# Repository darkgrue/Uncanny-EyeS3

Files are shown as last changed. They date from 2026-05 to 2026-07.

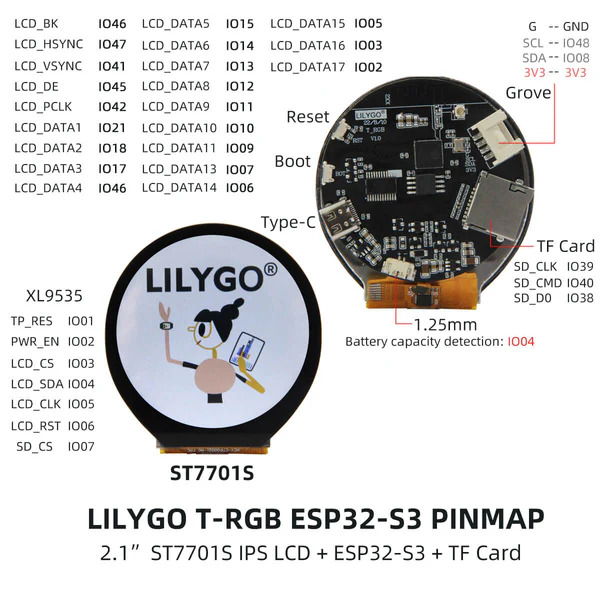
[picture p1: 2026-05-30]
docs/T-RGB-pinmap.jpg

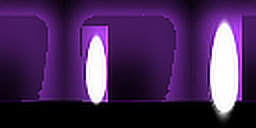
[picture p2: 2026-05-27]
resources/eyes/anime/iris.png

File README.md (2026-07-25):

# Uncanny-EyeS3

A port of the [Adafruit M4 Eyes](https://github.com/adafruit/Adafruit_Learning_System_Guides/tree/main/M4_Eyes) project to the LilyGO T-Display S3 AMOLED and T-RGB, with ESP32-specific rendering optimizations, WiiChuck puppeteering, light-driven pupil control, Gesture & Face Detection Sensor support for gaze direction, and multi-device synchronization over ESP-NOW.

This codebase draws on code and ideas from the following projects:

&emsp;https://github.com/adafruit/Uncanny_Eyes  
&emsp;https://github.com/adafruit/Adafruit_Learning_System_Guides/tree/main/M4_Eyes  
&emsp;https://github.com/chrismiller/TeensyEyes  
&emsp;https://github.com/MichaelMeissner/TeensyEyes/tree/meissner2  

Large portions of this codebase were ported and adapted with the assistance of AI coding tools, based on the logic and structure of the above projects. Sincere thanks to Adafruit, Phillip Burgess, Chris Miller, Michael Meissner, and the respective maintainers and contributors for their original work and for making it freely available to the community.

This project also includes a modified version of the LilyGO Arduino DriveBus Library, altered to correct functional issues.

---

## Supported Hardware

| Board | Display | Controller | Resolution |
| --- | --- | --- | --- |
| [LilyGo T-Display S3 AMOLED](https://lilygo.cc/en-us/products/t-display-s3-amoled-1-64?variant=45002266345653) | CO5300 (QSPI @ 80 MHz) | ESP32-S3 | 466×466 |
| [LilyGo T-RGB](https://lilygo.cc/en-us/products/t-rgb) | ST7701S (DPI) | ESP32-S3 | 480×480 |

**Optional peripherals:**

- Nintendo Wii Nunchuk (WiiChuck) — I2C puppeteering controller
- LDR photoresistor — ambient light-driven pupil dilation
- MAX44009 I2C ambient light sensor — alternative light sensor for pupil control
- DFRobot Gravity Gesture & Face Detection Sensor — AI face tracking for eye targeting
- MicroSD card — boot-time configuration via `/eyes_config.json` (ESP-NOW channel, security key, MAC allowlist)
- SY6970 — battery fuel gauge / charger (on-board, auto-initialized)

---

## Features

- **Autonomous animation** — saccadic eye movement with a lognormal amplitude distribution, centering bias, and sigmoid velocity easing for naturalistic motion
- **Realistic blinking** — three-phase FSM (close → pause → open) with randomized timing and burst probability
- **WiiChuck puppeteering** — joystick-driven eye targeting with edge-triggered blink/boop and hold commands for close/wide expressions
- **Face tracking** — AI gesture & face sensor directs gaze to the nearest detected face, overriding autonomous movement while yielding to WiiChuck joystick
- **Light sensor pupil control** — LDR photoresistor or MAX44009 I2C sensor drives pupil dilation; falls back to autonomous iris animation when not connected
- **Multi-eye ESP-NOW sync** — one device acts as controller, others follow with interpolated state at up to ~120 FPS; optional shared-key authentication prevents unauthorized devices from joining
- **SD card configuration** — optional `/eyes_config.json` at boot sets ESP-NOW channel, shared key, and MAC allowlist; firmware runs with safe defaults when no card is present
- **Runtime eye switching** — switch between registered eye designs over serial without reflashing
- **Double-buffered PSRAM rendering** — two RGB565 frame buffers with dirty-region tracking minimize display transfer overhead
- **User extension hooks** — `user_setup()` / `user_loop()` for custom sensor integrations

---

## Building

Requires [PlatformIO](https://platformio.org/).

```bash
# Build
pio run -e amoled          # T-Display S3 AMOLED (466×466)
pio run -e trgb            # T-RGB (480×480)

# Build and upload
pio run -e amoled --target upload
pio run -e trgb --target upload

# Serial monitor (115200 baud)
pio device monitor
```

---

## How It Works

### Rendering Pipeline

The firmware runs FreeRTOS tasks across two cores:

- **Core 1 — render task (~120 FPS):** `EyeAnimator::update()` advances the movement, blink, and iris state machines each frame. When `needsRender()` is true, `EyeRenderer::renderFrame()` draws the eye into the current PSRAM render buffer using precomputed polar and displacement lookup tables. Dirty region tracking limits each display transfer to only the pixels that changed.
- **Core 0 — display transfer + `loop()`:** The `eyeXfer` FreeRTOS task (priority 5) waits for a semaphore signal, then calls `directTransfer()` to stream the completed frame buffer to the display over QSPI. This task runs concurrently with rendering on Core 1 — as soon as `renderFrame()` finishes drawing, it signals the transfer task and immediately begins rendering the next frame into the other buffer. Arduino `loop()` also runs on Core 0 and handles serial commands and the 5-second status line.

### Eye Rendering

Each eye is defined by a precomputed set of lookup tables baked into C++ headers by `tablegen.py` and `geneye.py`:

- **Polar angle / distance maps** — map every pixel in the display circle to a polar coordinate in texture space
- **Spherical displacement map** — simulates the curvature of an eyeball
- **Radius lookup table** — `uint8_t[mapRadius²]` precomputed in `begin()`; eliminates `sqrt()` in the hot pixel loop
- **Eyelid tables** (optional) — per-column upper/lower eyelid Y positions for custom lid shapes

Textures are stored in **angle-major layout** (`T[angle * texH + radius]`) so that sequential radius lookups within a scanline are contiguous in memory. `EyeRenderer` builds a 256-entry angle→row pointer table at init time, replacing a per-pixel multiply with a single indexed load.

Per-scanline, zone limits (`xPupilLim`, `xIrisLim`) are computed once via the radius map, so the inner pixel loop uses integer comparisons instead of per-pixel radius checks. All lookup tables (angle map, radius map, iris texture, sclera texture) are copied into DRAM at `begin()` time to avoid PSRAM latency in the hot loop.

The frame buffer is stored big-endian (pre-swapped at write time), allowing the transfer task to stream it directly to the display via GDMA without a DRAM staging copy.

### Eye Movement

`EyeMovement` generates saccades using a lognormal amplitude distribution (matching natural human eye statistics), applies a centering bias after peripheral movements, and eases each movement with a sigmoid curve. Between saccades a configurable fixation pause (default 4–8 s) holds the eye still. When a WiiChuck is attached, direct joystick input overrides the autonomous mode.

### Multi-Eye Sync (ESP-NOW)

Any number of devices running the same firmware can synchronize over ESP-NOW:

1. The device with an active WiiChuck (joystick moved beyond the dead zone) becomes the controller.
2. The controller broadcasts an `EyeSyncMessage` each frame — eye X/Y, pupil factor, blink state, and expression command.
3. Follower devices receive the message and apply it via `EyeInterpolator`, which performs linear interpolation between received states for smooth local playback.
4. If no controller message is received within 100 ms, followers return to autonomous animation.

If no WiiChuck is connected to any device, all units run independently in autonomous mode.

ESP-NOW channel and security (shared key, MAC allowlist) are configured via the SD card config file; see [SD Card Configuration](#sd-card-configuration).

---

## Eye Configuration

### File Layout

Eye definitions live in `resources/eyes/`. Each eye has its own subdirectory:

```text
resources/eyes/
  default_eye/
    default_eye_466.eye    # AMOLED config
    default_eye_480.eye    # T-RGB config
    iris.png               # Optional iris texture
    sclera.png             # Optional sclera texture
    upper_lid.png          # Optional custom eyelid shape (grayscale)
    lower_lid.png
```

### Generating C++ Headers

Run `resources/tools/tablegen.py` to generate C++ header files with precomputed polar maps and displacement maps. These tables are shared across all eyes for a given display size. Header files are placed in `include/display/`.

```bash
# Regenerate for a single display type
python resources/tools/tablegen.py [display_type]

# Regenerate all display types
python resources/tools/tablegen.py -all
```

`display_type` is `default` (240x240), `amoled` (466x466), or `trgb` (480x480).

Output headers are named `display_240.h` (default), `display_466.h` (AMOLED), and `display_480.h` (T-RGB).

### `.eye` Config Format

All size values are fractions (0.0–1.0) of the display's smaller dimension, so a single config works across display sizes.

```json
{
    "name": "default_eye",
    "radiusFraction": 0.5,
    "backColor": 0,
    "squint": 0,
    "pupil": {
        "color": 0,
        "slitRadius": 0,
        "minFraction": 0.35,
        "maxFraction": 1.67
    },
    "iris": {
        "maxFraction": 0.5,
        "color": 65281,
        "angle": 0,
        "spin": 0,
        "iSpin": 0,
        "mirror": false,
        "maxTexW": 256,
        "maxTexH": 116
    },
    "sclera": {
        "color": 65535,
        "angle": 0,
        "spin": 0,
        "iSpin": 0,
        "mirror": false,
        "maxTexW": 128,
        "maxTexH": 64
    },
    "eyelid": {
        "color": 0,
        "normalClosure": 0.15,
        "wideClosure": 1.0,
        "tracking": true
    }
}
```

| Field | Description |
| --- | --- |
| `radiusFraction` | Eye radius as fraction of the smaller screen dimension |
| `backColor` | Background color behind the eye (RGB565) |
| `pupil.slitRadius` | `0.0` = round; fraction of iris radius for slit vertical half-height (e.g. `0.75`) |
| `pupil.minFraction` | Pupil radius at full constriction, as fraction of iris radius (brightest light) |
| `pupil.maxFraction` | Pupil radius at full dilation, as fraction of iris radius (darkest light) |
| `iris.maxFraction` | Iris radius as fraction of eye radius |
| `iris.spin` / `iSpin` | Continuous spin / fixed per-frame spin override |
| `iris.filename` | Optional PNG/BMP texture (relative path, auto-converted to RGB565) |
| `sclera.filename` | Optional sclera texture |
| `eyelid.upperFilename` | Optional custom lid images (upper, lower; must match display) |
| `iris.maxTexW` / `maxTexH` | Cap iris texture dimensions at generation time (pixels). Enforces DRAM budget. |
| `sclera.maxTexW` / `maxTexH` | Cap sclera texture dimensions at generation time (pixels). |
| `eyelid.normalClosure` | Eyelid coverage fraction at rest (0.0–1.0). Default: `0.0` |
| `eyelid.wideClosure` | Eyelid retraction fraction for `eyesWide()` (0.0–1.0). Default: `1.0` |
| `eyelid.tracking` | Eyelids track pupil vertical position. Default: `true` |

`eyelid.normalClosure` sets how much the lids close over the eye in the resting-open position. A value of `0.15` means the lids cover 15 % of the eye radius at rest. `eyesWide()` retracts the lids to the `wideClosure` fraction, making the expression visually distinct from the normal resting gap. The supplied eye definitions use `0.15` (default\_eye), `0.20` (hazel), and `0.05` (eagle).

`geneye.py` prints a DRAM budget warning at generation time if the combined angle map + radius map + iris texture + sclera texture exceeds ~170 KB (the threshold above which textures spill from DRAM into PSRAM and degrade render performance). Use `maxTexW`/`maxTexH` in the `.eye` config to bring an eye within budget.

### Adding a New Eye

1. Create `resources/eyes/<name>/` and write `<name>_466.eye` and `<name>_480.eye`.

2. Generate headers:

   ```bash
   python resources/tools/geneye.py -eye <eye_name>    # Generate header for specific eye
   python resources/tools/geneye.py -all               # Generate headers for all eyes
   python resources/tools/geneye.py -list              # List available eyes
   ```

3. Register in `include/EyeLibrary.h` under both board sections:

   ```cpp
   #include "eyes/<name>_466.h"   // in the AMOLED block
   // add &<name>::eye to s_eyeRegistry[] and increment s_eyeCount
   ```

4. Build and test: `pio run -e amoled` / `pio run -e trgb`.

---

## Runtime Eye Switching

Switch the active eye over serial without reflashing:

```text
E0    → switch to eye index 0 (anime)
E1    → switch to eye index 1 (default_eye)
E2    → switch to eye index 2 (dragon)
E3    → switch to eye index 3 (eagle)
E4    → switch to eye index 4 (hazel)
E5    → switch to eye index 5 (leopard)
```

The command is parsed in `loop()` and calls `EyeAnimator::setEyeIndex()`, which reinitializes the renderer with the new eye definition.

---

## Display Orientation

For builds where the display is physically mounted rotated 180°, send a command over
serial to flip the image. The change applies immediately and lasts for the current
power cycle only — it is never written back to the SD card.

```text
U0    → normal orientation
U1    → upside-down (180° flip)
```

If no display is initialized, the command prints `Display not available.` and has
no effect.

A boot-time default can be set via the `display` section in `/eyes_config.json` —
see [SD Card Configuration](#sd-card-configuration):

```json
{
  "display": {
    "upsideDown": false
  }
}
```

On the AMOLED board this is a single display-controller register write (the panel
itself flips the scan-out), so it costs nothing per frame. On the T-RGB board the
flip is applied during the existing per-row buffer copy in `directTransfer()`,
adding only a per-row pixel reversal rather than any change to the render loop
itself.

---

## WiiChuck Controller

### Wiring

| WiiChuck Pin | T-Display S3 AMOLED | T-RGB |
| --- | --- | --- |
| Data (SDA) | GPIO 7 | GPIO 48 |
| Clock (SCL)  | GPIO 6 | GPIO 8  |
| 3.3V | 3.3V | 3.3V |
| GND | GND | GND |

I2C address: `0x52`, bus speed: 400 kHz.

### Controls

| Input | Behavior |
| --- | --- |
| Joystick (active) | Direct eye position; overrides autonomous movement |
| Joystick (centered) | Returns to autonomous wandering after current saccade finishes |
| Z press | Single blink (edge-triggered) |
| C hold | Eyes go wide — eyelids retract beyond the normal resting gap |
| C + Z (chord) | Boop expression (fires when the second button lands) |

Buttons work independently of the joystick: you can blink or go wide while the joystick is centred.

Joystick values are raw 0–255 with center at 128. A ±10 dead zone prevents drift. Control returns to autonomous mode when the joystick is centered.

The WiiChuck is optional — the firmware prints a warning at startup if not found and continues with autonomous animation.

---

## Light Sensor (Pupil Control)

Two sensor types are supported:

- **LDR photoresistor** — connect a voltage divider to GPIO 5 (`LIGHT_PIN`). Auto-detected at startup by sampling for minimum variance.
- **MAX44009 I2C ambient light sensor** — connected via the I2C bus (same as WiiChuck). Auto-detected on startup.

When a light sensor is connected:

- Bright light → constricted pupil
- Dim light → dilated pupil
- Hippus oscillation (natural pupillary unrest) still applies on top of the sensor-driven baseline
- Transition speed is controlled by `PUPIL_SMOOTH_ALPHA` in `src/animation/EyeMovement.h` (lower = slower)

If no sensor is found, autonomous iris animation is used instead.

---

## Gesture & Face Detection Sensor

The [DFRobot Gravity Offline Edge AI Gesture & Face Detection](https://www.dfrobot.com/product-2914.html) sensor connects to the same I2C bus as the WiiChuck (see [WiiChuck Controller](#wiichuck-controller) for pin assignments). It is auto-detected at startup; if not found, the firmware continues without face tracking.

I2C address: `0x72`.

When at least one face is detected with a confidence score at or above the minimum threshold (default 50 out of 100), the eye tracks the nearest face. When no face is visible the eye returns to autonomous random movement.

Face position is reported in camera pixel coordinates. The default normalization assumes a 320×240 frame; pass custom width/height values to the `GestureFaceInput` constructor if the sensor reports a different resolution. Call `setMinScore()` to adjust the confidence threshold.

---

## SD Card Configuration

An optional MicroSD card provides boot-time configuration without reflashing. The card is read once at startup and then released — it is not required while the firmware is running.

### Pinout

Both boards use the same dedicated SPI pins for the SD card:

| SD Pin | GPIO |
| --- | ---- |
| CS | 38 |
| MOSI | 39 |
| MISO | 40 |
| SCLK | 41 |

### Config File

Place `/eyes_config.json` in the root directory of the card:

```json
{
  "eye": {
    "startIndex": 1
  },
  "display": {
    "upsideDown": false
  },
  "network": {
    "channel": 1,
    "key": "SharedPassphrase",
    "allowed_macs": [
      "AA:BB:CC:DD:EE:FF",
      "11:22:33:44:55:66"
    ],
    "forceController": false
  }
}
```

| Field | Type | Default  | Description |
| --- | --- | --- | --- |
| `eye.startIndex` | int | `0` | Eye index to load at startup; see Runtime Eye Switching for names |
| `display.upsideDown` | bool | `false`  | Boot-time default for a 180-degree flip (see Display Orientation) |
| `network.channel` | int | `1` | ESP-NOW WiFi channel (1–13); must match across all synchronized devices |
| `network.key` | string | _(none)_ | Shared passphrase or 32-hex-digit key; omit to disable authentication |
| `network.allowed_macs` | array  | _(none)_ | MAC allowlist; omit to accept any device with the correct key |
| `network.forceController` | bool | `false`  | Broadcast as controller with no WiiChuck/gesture input attached (see below) |

### Syncing Devices Without a WiiChuck

Normally, a device only broadcasts its eye state over ESP-NOW if it has an active WiiChuck or gesture-tracking input attached — that device becomes the controller, and others follow. If none of your devices have such an input, they'll each run autonomous animation independently and never show any ESP-NOW peers.

To sync two or more purely-autonomous devices, set `network.forceController: true` in the config on exactly **one** device in the group. That device broadcasts its (autonomous) state; the others should leave `forceController` unset (or `false`) so they follow it.

### Key Formats

The `key` field accepts two formats:

- **Passphrase** — any string up to 16 characters, zero-padded internally to 16 bytes.
- **Hex key** — exactly 32 hexadecimal characters (e.g. `"0123456789ABCDEF0123456789ABCDEF"`), decoded directly to 16 raw bytes.

Either format can be used interchangeably as long as the resulting 16-byte value is identical on all devices.

### Security Model

When a `key` is configured, the firmware derives a 32-bit token from it and stamps every outgoing ESP-NOW packet. Incoming packets are silently discarded if:

- The token does not match (sender has a different or absent key).
- An `allowed_macs` list is configured and the sender MAC is not in it.

Devices sharing the same key communicate normally. Devices with different keys — or no key — silently ignore each other without producing errors. If no key is configured, any device on the channel is accepted.

**All devices in a synchronized group must use matching keys.**

The `allowed_macs` list provides an additional layer of access control independent of the key. If both are configured, a packet must pass both checks.

### Graceful Degradation

The firmware starts normally regardless of SD card state:

- No SD card inserted
- Card present but `/eyes_config.json` missing
- Config file present but malformed JSON

In all cases the defaults are used: channel 1, no authentication, all senders accepted. A message is printed to serial indicating which condition was detected.

---

## Input Priority

### Movement Priority

The first active source in the following order controls eye position each frame:

1. **WiiChuck joystick** — when the joystick is tilted beyond the ±10 dead zone, it takes exclusive control and suppresses all other movement sources.
2. **Gesture & face detection** — when a face is detected with sufficient confidence, the eye tracks the face. Control is released immediately when no face is visible.
3. **ESP-NOW network controller** — a paired controller device broadcasts its state; followers apply it when data is fresher than 100 ms.
4. **Autonomous random saccades** — lognormal amplitude distribution with centering bias and sigmoid easing; the default when no input is active.

### Pupil Sizing Priority

Pupil size is driven by whichever source is available:

1. **Light sensor (LDR or MAX44009)** — maps ambient light to pupil dilation at up to 100 Hz with time-based exponential smoothing when connected.
2. **Autonomous iris animation** — simulates natural pupillary unrest using lognormal targets and smoothstep easing when no light sensor is present.

Face detection and ESP-NOW do not affect pupil size.

---

## User Extension Hooks

Implement `user_setup()` and `user_loop()` in `src/user/user_hooks.cpp` to add custom behavior without modifying core code. `user_loop()` runs during the render task — keep it short.

Available expression calls from either hook:

```cpp
eyesBlink();    // trigger a single blink
eyesBoop();     // trigger a boop expression
eyesClose();    // hold eyelids closed
eyesWide();     // hold eyelids wide
eyesNormal();   // return to normal tracking
```

---

## Project Structure

```text
src/
  main.cpp                  # Entry point, FreeRTOS task setup
  eye/
    EyeAnimator             # Central animation state machine
    EyeRenderer             # Per-pixel polar-map rendering, double-buffered PSRAM
    EyelidRenderer          # Eyelid shape rendering (procedural or custom)
    EyeConfig.h             # Runtime configuration struct
  animation/
    EyeMovement             # Saccadic movement with lognormal distribution
    BlinkFSM                # Three-phase blink state machine
  display/
    AMOLEDDisplay           # CO5300 QSPI driver (466×466)
    TRGBDisplay             # ST7701S DPI driver (480×480)
  input/
    WiiChuck                # Wii Nunchuk I2C driver
    LightSensor             # LDR photoresistor pupil control
    GestureFaceInput        # DFRobot Gravity Gesture & Face Detection sensor
  network/
    EyeSync                 # ESP-NOW controller/follower synchronization
  config/
    SDConfig                # SD card boot-time configuration reader
  common/
    DisplayHAL.h            # Abstract display interface
    EyeState.h              # Shared state structs and enums
    DisplayGeometry.h       # Polar maps, circular clipping
  debug/
    DebugOverlay            # FPS + battery HUD (build flag: DEBUG_OVERLAY_ENABLED)
  user/
    user_hooks.cpp          # User extension template

include/
  eyes.h                    # EyeDefinition struct and helper macros
  EyeLibrary.h              # Eye registry (s_eyeRegistry[], s_eyeCount)
  BoardPins.h               # GPIO pin definitions per board
  eyes/
    *_466.h                 # Generated AMOLED eye headers
    *_480.h                 # Generated T-RGB eye headers

resources/
  tools/
    tablegen.py             # Display polar-map / displacement table generator
    geneye.py               # Eye header generator (angle-major textures, DRAM budget check)
    test_geneye_texture.py  # Texture layout unit tests
  eyes/
    <eye_name>/
      <eye_name>_466.eye    # AMOLED eye config
      <eye_name>_480.eye    # T-RGB eye config
      *.png / *.bmp         # Optional textures and eyelid images
```

---

## Build Flags

Defined in `platformio.ini` under `[esp32base]`:

| Flag | Purpose |
| --- | --- |
| `FDEBUG` | Enable debug serial output |
| `DEBUG_OVERLAY_ENABLED` | Show FPS/battery HUD on display |
| `DEBUG_FPS_ENABLED` | Print FPS and render/transfer timing to serial |
| `CORE_DEBUG_LEVEL=3` | ESP-IDF log verbosity (info) |
| `BUILDVER=0.0.1` | Embedded firmware version string |
| `ESP32QSPI_MAX_PIXELS_AT_ONCE=16384`  | SPI DMA chunk size (patched library); 16384 pixels = 32 KB buffer |

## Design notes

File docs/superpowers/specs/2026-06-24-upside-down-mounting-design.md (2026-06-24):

# Upside-Down Mounting Design

**Date:** 2026-06-24
**Status:** Approved
**Scope:** `DisplayHAL`, `AMOLEDDisplay`, `TRGBDisplay`, `SDConfig`, `EyeConfig`, `main.cpp`

---

## Problem

Some physical builds need a display mounted rotated 180° relative to its native
orientation (e.g. cable routing constraints in the housing). The firmware needs a
way to compensate for this — flipping the displayed image 180° — without adding
per-pixel cost to the 120 FPS render/transfer hot path.

The setting must be:
- Per physical display (a property of how *this device* is mounted, not of which
  eye graphic or eye index is currently loaded).
- Settable at runtime via serial command, taking effect immediately.
- Configurable with a boot-time default via `/eyes_config.json` on the SD card.
- Session-only — runtime changes do not persist back to the SD card.

---

## Solution: Flip in the display layer, not the renderer

`EyeRenderer` always renders in standard top-left-origin orientation — unchanged.
Each `DisplayHAL` implementation is already responsible for getting that buffer onto
its physical panel; the 180° compensation belongs there; the two backends need
different mechanisms because their hardware differs.

`DisplayHAL::setRotation(uint8_t rotation)` already exists in the interface
([DisplayHAL.h:54](../../../src/common/DisplayHAL.h)). `rotation = 2` is reused as
the "180°" value on both backends, consistent with the existing Arduino_GFX
convention. No new interface method is added.

### AMOLED (CO5300, QSPI) — already correct, no code change

`AMOLEDDisplay::setRotation()` ([AMOLEDDisplay.cpp:247-254](../../../src/display/AMOLEDDisplay.cpp))
calls `m_gfx->setRotation(rotation)`. For the CO5300, `Arduino_CO5300::setRotation(2)`
writes the controller's MADCTL register with both X- and Y-axis flip bits
([Arduino_CO5300.cpp:41-62](../../../.pio/libdeps/amoled/GFX%20Library%20for%20Arduino/src/display/Arduino_CO5300.cpp)).
This is a single register write — the display controller itself flips the image as
it scans into the physical panel. Because `EyeRenderer`'s async transfer always blits
the full `0,0 → displaySize,displaySize` buffer ([EyeRenderer.cpp:415](../../../src/eye/EyeRenderer.cpp)),
one register write at orientation-change time reorients everything (eye content and
debug overlay) with zero ongoing per-frame cost. `_xStart`/`_yStart` offset handling
for rotation 2 resolves to `(COL_OFFSET2, ROW_OFFSET2)` = `(0, 0)` for this panel's
constructor parameters, so no addressing-window correction is needed.

### T-RGB (ST7701S, DPI) — flip applied during the existing per-row copy

`TRGBDisplay::setRotation()` ([TRGBDisplay.cpp:128-134](../../../src/display/TRGBDisplay.cpp))
currently only forwards to `gfx->setRotation()`, which sets a software variable in
the base `Arduino_GFX` class — it does **not** send any MADCTL-equivalent command
(`Arduino_RGB_Display` does not override `setRotation`), and it has no effect on
`directTransfer`'s raw `memcpy` into the PSRAM framebuffer.

Change `TRGBDisplay::setRotation()` to:
1. Keep calling `gfx->setRotation(rotation)` — this keeps the debug overlay
   (`fillRect`/`drawString`, which go through normal Arduino_GFX draw calls) correctly
   placed after a flip. Low frequency; cost is irrelevant.
2. Store `m_rotation180 = (rotation == 2)` on the `TRGBDisplay` instance.

Change `TRGBDisplay::directTransfer()` ([TRGBDisplay.cpp:190-209](../../../src/display/TRGBDisplay.cpp))
to branch on `m_rotation180`:
- **Normal (false):** unchanged — per-row `memcpy`.
- **Flipped (true):** iterate source rows back-to-front (`srcH-1` down to `0`) when
  computing the destination row — free, same total `memcpy` byte count, just a
  different row-to-row mapping — and within each row, copy pixels in reverse order
  (`dstRow[w-1-i] = srcRow[i]`). This is the one place that adds real per-frame cost:
  a per-pixel copy loop instead of a single `memcpy` for each row, on a ≤480-pixel
  row, once per frame. Negligible next to the per-pixel rendering cost already paid
  earlier in the same frame, and it does not touch `EyeRenderer`'s hot loop at all.

---

## Runtime control

Add a new single-character serial command to the existing dispatcher in
`main.cpp` ([main.cpp:677-692](../../../src/main.cpp)), alongside the existing `E<n>`
eye-switch command:

```cpp
else if (c == 'U')
{
  int flag = Serial.parseInt();
  s_display->setRotation(flag ? 2 : 0);
  Serial.printf("Display %s\n", flag ? "upside-down" : "normal");
}
```

`U1` sets upside-down, `U0` restores normal. Takes effect immediately. This is
session-only — it does not write back to the SD card.

---

## Boot-time default: `/eyes_config.json`

Add a new top-level `display` section (separate from the existing `eye` section,
since this is a property of the physical device, not of the eye graphic or index):

```json
{
  "display": {
    "upsideDown": false
  }
}
```

**`SDConfig` changes:**
- `DeviceConfig` ([SDConfig.h:47-56](../../../src/config/SDConfig.h)) gains
  `bool displayUpsideDown;` (default `false`, set in `applyDefaults()`).
- `SDConfig::load()` ([SDConfig.cpp:25-112](../../../src/config/SDConfig.cpp)) gains a
  `display` section parse block, mirroring the existing `eye`/`network` block style:
  ```cpp
  JsonObject disp = doc["display"];
  if (!disp.isNull())
  {
    cfg.displayUpsideDown = disp["upsideDown"] | false;
  }
  ```

**Applying the default:** in `main.cpp` setup, after `s_display` is assigned and
`begin()` has run, call:
```cpp
s_display->setRotation(s_config.displayUpsideDown ? 2 : 0);
```
This is the same code path as the runtime `U` command, so behavior is identical
whether the orientation is set at boot or live.

`EyeProjectConfig` ([EyeConfig.h](../../../src/eye/EyeConfig.h)) is not changed —
orientation is consumed directly from `DeviceConfig` into `DisplayHAL`, not routed
through the animator/renderer config struct, since `EyeRenderer` is intentionally
untouched by this feature.

---

## Files Changed

| File | Nature of change |
|---|---|
| `src/display/TRGBDisplay.h` / `.cpp` | `setRotation()` stores `m_rotation180`; `directTransfer()` branches to a reversed row+pixel copy when flipped |
| `src/display/AMOLEDDisplay.h` / `.cpp` | No change — existing `setRotation()` already sufficient |
| `src/common/DisplayHAL.h` | No change — reuses existing `setRotation(uint8_t)` |
| `src/config/SDConfig.h` / `.cpp` | New `DeviceConfig::displayUpsideDown` field; new `display` JSON section parsing |
| `src/main.cpp` | New `U<0|1>` serial command; apply `s_config.displayUpsideDown` to `s_display` once at startup |

No changes to `EyeRenderer`, `EyelidRenderer`, `EyeAnimator`, `eyes.h`, or any
generated eye headers — this feature is entirely contained in the display/config
layer.

---

## Testing

- **AMOLED:** send `U1` over serial, confirm the eye and debug overlay (if enabled)
  both appear rotated 180°; send `U0`, confirm restoration. Confirm FPS is unaffected
  (expected — hardware-only change).
- **T-RGB:** same `U1`/`U0` check. Measure `directTransfer` duration before/after to
  confirm the reversed-copy cost is negligible relative to total frame time.
- **SD config:** set `"display": {"upsideDown": true}` in `/eyes_config.json`, confirm
  boot starts flipped; confirm a runtime `U0` overrides it for the session without
  rewriting the file.
- **No SD card / missing `display` section:** confirm default is normal orientation
  (false), matching existing `applyDefaults()` behavior for absent sections.

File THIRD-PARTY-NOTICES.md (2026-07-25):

# Third-Party Notices

This project incorporates open-source third-party software. The notices and licenses for these dependencies are detailed below.

---

## 1. Uncanny_Eyes
* **Source:** https://github.com/adafruit/Uncanny_Eyes
* **Copyright:** Written by Phil Burgess / Paint Your Dragon for Adafruit Industries.

MIT license. [LICENSE file not provided by author.]

## 2. Adafruit_Learning_System_Guides / M4_Eyes
* **Source:** https://github.com/adafruit/Adafruit_Learning_System_Guides/tree/main/M4_Eyes
* **Copyright:** 2019 Phillip Burgess for Adafruit Industries.

MIT License

Copyright (c) 2018 Adafruit Industries

Permission is hereby granted, free of charge, to any person obtaining a copy
of this software and associated documentation files (the "Software"), to deal
in the Software without restriction, including without limitation the rights
to use, copy, modify, merge, publish, distribute, sublicense, and/or sell
copies of the Software, and to permit persons to whom the Software is
furnished to do so, subject to the following conditions:

The above copyright notice and this permission notice shall be included in all
copies or substantial portions of the Software.

THE SOFTWARE IS PROVIDED "AS IS", WITHOUT WARRANTY OF ANY KIND, EXPRESS OR
IMPLIED, INCLUDING BUT NOT LIMITED TO THE WARRANTIES OF MERCHANTABILITY,
FITNESS FOR A PARTICULAR PURPOSE AND NONINFRINGEMENT. IN NO EVENT SHALL THE
AUTHORS OR COPYRIGHT HOLDERS BE LIABLE FOR ANY CLAIM, DAMAGES OR OTHER
LIABILITY, WHETHER IN AN ACTION OF CONTRACT, TORT OR OTHERWISE, ARISING FROM,
OUT OF OR IN CONNECTION WITH THE SOFTWARE OR THE USE OR OTHER DEALINGS IN THE
SOFTWARE.

## 3. TeensyEyes
* **Source:** https://github.com/chrismiller/TeensyEyes
* **Copyright:** 2022 Chris Miller

MIT License

Copyright (c) 2022 Chris Miller

Permission is hereby granted, free of charge, to any person obtaining a copy
of this software and associated documentation files (the "Software"), to deal
in the Software without restriction, including without limitation the rights
to use, copy, modify, merge, publish, distribute, sublicense, and/or sell
copies of the Software, and to permit persons to whom the Software is
furnished to do so, subject to the following conditions:

The above copyright notice and this permission notice shall be included in all
copies or substantial portions of the Software.

THE SOFTWARE IS PROVIDED "AS IS", WITHOUT WARRANTY OF ANY KIND, EXPRESS OR
IMPLIED, INCLUDING BUT NOT LIMITED TO THE WARRANTIES OF MERCHANTABILITY,
FITNESS FOR A PARTICULAR PURPOSE AND NONINFRINGEMENT. IN NO EVENT SHALL THE
AUTHORS OR COPYRIGHT HOLDERS BE LIABLE FOR ANY CLAIM, DAMAGES OR OTHER
LIABILITY, WHETHER IN AN ACTION OF CONTRACT, TORT OR OTHERWISE, ARISING FROM,
OUT OF OR IN CONNECTION WITH THE SOFTWARE OR THE USE OR OTHER DEALINGS IN THE
SOFTWARE.

## 4. TeensyEyes
* **Source:** https://github.com/MichaelMeissner/TeensyEyes/tree/meissner2
* **Copyright:** Michael Meissner

MIT License

Copyright (c) 2022 Chris Miller [sic]

Permission is hereby granted, free of charge, to any person obtaining a copy
of this software and associated documentation files (the "Software"), to deal
in the Software without restriction, including without limitation the rights
to use, copy, modify, merge, publish, distribute, sublicense, and/or sell
copies of the Software, and to permit persons to whom the Software is
furnished to do so, subject to the following conditions:

The above copyright notice and this permission notice shall be included in all
copies or substantial portions of the Software.

THE SOFTWARE IS PROVIDED "AS IS", WITHOUT WARRANTY OF ANY KIND, EXPRESS OR
IMPLIED, INCLUDING BUT NOT LIMITED TO THE WARRANTIES OF MERCHANTABILITY,
FITNESS FOR A PARTICULAR PURPOSE AND NONINFRINGEMENT. IN NO EVENT SHALL THE
AUTHORS OR COPYRIGHT HOLDERS BE LIABLE FOR ANY CLAIM, DAMAGES OR OTHER
LIABILITY, WHETHER IN AN ACTION OF CONTRACT, TORT OR OTHERWISE, ARISING FROM,
OUT OF OR IN CONNECTION WITH THE SOFTWARE OR THE USE OR OTHER DEALINGS IN THE
SOFTWARE.

## 5. Arduino_DriveBus
* **Source:** https://github.com/Xinyuan-LilyGO/T-Display-S3-AMOLED-1.43-1.75/tree/main/libraries/Arduino_DriveBus
* **Copyright:** LilyGO

                    GNU GENERAL PUBLIC LICENSE
                       Version 3, 29 June 2007

 Copyright (C) 2007 Free Software Foundation, Inc. <https://fsf.org/>
 Everyone is permitted to copy and distribute verbatim copies
 of this license document, but changing it is not allowed.

                            Preamble

  The GNU General Public License is a free, copyleft license for
software and other kinds of works.

  The licenses for most software and other practical works are designed
to take away your freedom to share and change the works.  By contrast,
the GNU General Public License is intended to guarantee your freedom to
share and change all versions of a program--to make sure it remains free
software for all its users.  We, the Free Software Foundation, use the
GNU General Public License for most of our software; it applies also to
any other work released this way by its authors.  You can apply it to
your programs, too.

  When we speak of free software, we are referring to freedom, not
price.  Our General Public Licenses are designed to make sure that you
have the freedom to distribute copies of free software (and charge for
them if you wish), that you receive source code or can get it if you
want it, that you can change the software or use pieces of it in new
free programs, and that you know you can do these things.

  To protect your rights, we need to prevent others from denying you
these rights or asking you to surrender the rights.  Therefore, you have
certain responsibilities if you distribute copies of the software, or if
you modify it: responsibilities to respect the freedom of others.

  For example, if you distribute copies of such a program, whether
gratis or for a fee, you must pass on to the recipients the same
freedoms that you received.  You must make sure that they, too, receive
or can get the source code.  And you must show them these terms so they
know their rights.

  Developers that use the GNU GPL protect your rights with two steps:
(1) assert copyright on the software, and (2) offer you this License
giving you legal permission to copy, distribute and/or modify it.

  For the developers' and authors' protection, the GPL clearly explains
that there is no warranty for this free software.  For both users' and
authors' sake, the GPL requires that modified versions be marked as
changed, so that their problems will not be attributed erroneously to
authors of previous versions.

  Some devices are designed to deny users access to install or run
modified versions of the software inside them, although the manufacturer
can do so.  This is fundamentally incompatible with the aim of
protecting users' freedom to change the software.  The systematic
pattern of such abuse occurs in the area of products for individuals to
use, which is precisely where it is most unacceptable.  Therefore, we
have designed this version of the GPL to prohibit the practice for those
products.  If such problems arise substantially in other domains, we
stand ready to extend this provision to those domains in future versions
of the GPL, as needed to protect the freedom of users.

  Finally, every program is threatened constantly by software patents.
States should not allow patents to restrict development and use of
software on general-purpose computers, but in those that do, we wish to
avoid the special danger that patents applied to a free program could
make it effectively proprietary.  To prevent this, the GPL assures that
patents cannot be used to render the program non-free.

  The precise terms and conditions for copying, distribution and
modification follow.

                       TERMS AND CONDITIONS

  0. Definitions.

  "This License" refers to version 3 of the GNU General Public License.

  "Copyright" also means copyright-like laws that apply to other kinds of
works, such as semiconductor masks.

  "The Program" refers to any copyrightable work licensed under this
License.  Each licensee is addressed as "you".  "Licensees" and
"recipients" may be individuals or organizations.

  To "modify" a work means to copy from or adapt all or part of the work
in a fashion requiring copyright permission, other than the making of an
exact copy.  The resulting work is called a "modified version" of the
earlier work or a work "based on" the earlier work.

  A "covered work" means either the unmodified Program or a work based
on the Program.

  To "propagate" a work means to do anything with it that, without
permission, would make you directly or secondarily liable for
infringement under applicable copyright law, except executing it on a
computer or modifying a private copy.  Propagation includes copying,
distribution (with or without modification), making available to the
public, and in some countries other activities as well.

  To "convey" a work means any kind of propagation that enables other
parties to make or receive copies.  Mere interaction with a user through
a computer network, with no transfer of a copy, is not conveying.

  An interactive user interface displays "Appropriate Legal Notices"
to the extent that it includes a convenient and prominently visible
feature that (1) displays an appropriate copyright notice, and (2)
tells the user that there is no warranty for the work (except to the
extent that warranties are provided), that licensees may convey the
work under this License, and how to view a copy of this License.  If
the interface presents a list of user commands or options, such as a
menu, a prominent item in the list meets this criterion.

  1. Source Code.

  The "source code" for a work means the preferred form of the work
for making modifications to it.  "Object code" means any non-source
form of a work.

  A "Standard Interface" means an interface that either is an official
standard defined by a recognized standards body, or, in the case of
interfaces specified for a particular programming language, one that
is widely used among developers working in that language.

  The "System Libraries" of an executable work include anything, other
than the work as a whole, that (a) is included in the normal form of
packaging a Major Component, but which is not part of that Major
Component, and (b) serves only to enable use of the work with that
Major Component, or to implement a Standard Interface for which an
implementation is available to the public in source code form.  A
"Major Component", in this context, means a major essential component
(kernel, window system, and so on) of the specific operating system
(if any) on which the executable work runs, or a compiler used to
produce the work, or an object code interpreter used to run it.

  The "Corresponding Source" for a work in object code form means all
the source code needed to generate, install, and (for an executable
work) run the object code and to modify the work, including scripts to
control those activities.  However, it does not include the work's
System Libraries, or general-purpose tools or generally available free
programs which are used unmodified in performing those activities but
which are not part of the work.  For example, Corresponding Source
includes interface definition files associated with source files for
the work, and the source code for shared libraries and dynamically
linked subprograms that the work is specifically designed to require,
such as by intimate data communication or control flow between those
subprograms and other parts of the work.

  The Corresponding Source need not include anything that users
can regenerate automatically from other parts of the Corresponding
Source.

  The Corresponding Source for a work in source code form is that
same work.

  2. Basic Permissions.

  All rights granted under this License are granted for the term of
copyright on the Program, and are irrevocable provided the stated
conditions are met.  This License explicitly affirms your unlimited
permission to run the unmodified Program.  The output from running a
covered work is covered by this License only if the output, given its
content, constitutes a covered work.  This License acknowledges your
rights of fair use or other equivalent, as provided by copyright law.

  You may make, run and propagate covered works that you do not
convey, without conditions so long as your license otherwise remains
in force.  You may convey covered works to others for the sole purpose
of having them make modifications exclusively for you, or provide you
with facilities for running those works, provided that you comply with
the terms of this License in conveying all material for which you do
not control copyright.  Those thus making or running the covered works
for you must do so exclusively on your behalf, under your direction
and control, on terms that prohibit them from making any copies of
your copyrighted material outside their relationship with you.

  Conveying under any other circumstances is permitted solely under
the conditions stated below.  Sublicensing is not allowed; section 10
makes it unnecessary.

  3. Protecting Users' Legal Rights From Anti-Circumvention Law.

  No covered work shall be deemed part of an effective technological
measure under any applicable law fulfilling obligations under article
11 of the WIPO copyright treaty adopted on 20 December 1996, or
similar laws prohibiting or restricting circumvention of such
measures.

  When you convey a covered work, you waive any legal power to forbid
circumvention of technological measures to the extent such circumvention
is effected by exercising rights under this License with respect to
the covered work, and you disclaim any intention to limit operation or
modification of the work as a means of enforcing, against the work's
users, your or third parties' legal rights to forbid circumvention of
technological measures.

  4. Conveying Verbatim Copies.

  You may convey verbatim copies of the Program's source code as you
receive it, in any medium, provided that you conspicuously and
appropriately publish on each copy an appropriate copyright notice;
keep intact all notices stating that this License and any
non-permissive terms added in accord with section 7 apply to the code;
keep intact all notices of the absence of any warranty; and give all
recipients a copy of this License along with the Program.

  You may charge any price or no price for each copy that you convey,
and you may offer support or warranty protection for a fee.

  5. Conveying Modified Source Versions.

  You may convey a work based on the Program, or the modifications to
produce it from the Program, in the form of source code under the
terms of section 4, provided that you also meet all of these conditions:

    a) The work must carry prominent notices stating that you modified
    it, and giving a relevant date.

    b) The work must carry prominent notices stating that it is
    released under this License and any conditions added under section
    7.  This requirement modifies the requirement in section 4 to
    "keep intact all notices".

    c) You must license the entire work, as a whole, under this
    License to anyone who comes into possession of a copy.  This
    License will therefore apply, along with any applicable section 7
    additional terms, to the whole of the work, and all its parts,
    regardless of how they are packaged.  This License gives no
    permission to license the work in any other way, but it does not
    invalidate such permission if you have separately received it.

    d) If the work has interactive user interfaces, each must display
    Appropriate Legal Notices; however, if the Program has interactive
    interfaces that do not display Appropriate Legal Notices, your
    work need not make them do so.

  A compilation of a covered work with other separate and independent
works, which are not by their nature extensions of the covered work,
and which are not combined with it such as to form a larger program,
in or on a volume of a storage or distribution medium, is called an
"aggregate" if the compilation and its resulting copyright are not
used to limit the access or legal rights of the compilation's users
beyond what the individual works permit.  Inclusion of a covered work
in an aggregate does not cause this License to apply to the other
parts of the aggregate.

  6. Conveying Non-Source Forms.

  You may convey a covered work in object code form under the terms
of sections 4 and 5, provided that you also convey the
machine-readable Corresponding Source under the terms of this License,
in one of these ways:

    a) Convey the object code in, or embodied in, a physical product
    (including a physical distribution medium), accompanied by the
    Corresponding Source fixed on a durable physical medium
    customarily used for software interchange.

    b) Convey the object code in, or embodied in, a physical product
    (including a physical distribution medium), accompanied by a
    written offer, valid for at least three years and valid for as
    long as you offer spare parts or customer support for that product
    model, to give anyone who possesses the object code either (1) a
    copy of the Corresponding Source for all the software in the
    product that is covered by this License, on a durable physical
    medium customarily used for software interchange, for a price no
    more than your reasonable cost of physically performing this
    conveying of source, or (2) access to copy the
    Corresponding Source from a network server at no charge.

    c) Convey individual copies of the object code with a copy of the
    written offer to provide the Corresponding Source.  This
    alternative is allowed only occasionally and noncommercially, and
    only if you received the object code with such an offer, in accord
    with subsection 6b.

    d) Convey the object code by offering access from a designated
    place (gratis or for a charge), and offer equivalent access to the
    Corresponding Source in the same way through the same place at no
    further charge.  You need not require recipients to copy the
    Corresponding Source along with the object code.  If the place to
    copy the object code is a network server, the Corresponding Source
    may be on a different server (operated by you or a third party)
    that supports equivalent copying facilities, provided you maintain
    clear directions next to the object code saying where to find the
    Corresponding Source.  Regardless of what server hosts the
    Corresponding Source, you remain obligated to ensure that it is
    available for as long as needed to satisfy these requirements.

    e) Convey the object code using peer-to-peer transmission, provided
    you inform other peers where the object code and Corresponding
    Source of the work are being offered to the general public at no
    charge under subsection 6d.

  A separable portion of the object code, whose source code is excluded
from the Corresponding Source as a System Library, need not be
included in conveying the object code work.

  A "User Product" is either (1) a "consumer product", which means any
tangible personal property which is normally used for personal, family,
or household purposes, or (2) anything designed or sold for incorporation
into a dwelling.  In determining whether a product is a consumer product,
doubtful cases shall be resolved in favor of coverage.  For a particular
product received by a particular user, "normally used" refers to a
typical or common use of that class of product, regardless of the status
of the particular user or of the way in which the particular user
actually uses, or expects or is expected to use, the product.  A product
is a consumer product regardless of whether the product has substantial
commercial, industrial or non-consumer uses, unless such uses represent
the only significant mode of use of the product.

  "Installation Information" for a User Product means any methods,
procedures, authorization keys, or other information required to install
and execute modified versions of a covered work in that User Product from
a modified version of its Corresponding Source.  The information must
suffice to ensure that the continued functioning of the modified object
code is in no case prevented or interfered with solely because
modification has been made.

  If you convey an object code work under this section in, or with, or
specifically for use in, a User Product, and the conveying occurs as
part of a transaction in which the right of possession and use of the
User Product is transferred to the recipient in perpetuity or for a
fixed term (regardless of how the transaction is characterized), the
Corresponding Source conveyed under this section must be accompanied
by the Installation Information.  But this requirement does not apply
if neither you nor any third party retains the ability to install
modified object code on the User Product (for example, the work has
been installed in ROM).

  The requirement to provide Installation Information does not include a
requirement to continue to provide support service, warranty, or updates
for a work that has been modified or installed by the recipient, or for
the User Product in which it has been modified or installed.  Access to a
network may be denied when the modification itself materially and
adversely affects the operation of the network or violates the rules and
protocols for communication across the network.

  Corresponding Source conveyed, and Installation Information provided,
in accord with this section must be in a format that is publicly
documented (and with an implementation available to the public in
source code form), and must require no special password or key for
unpacking, reading or copying.

  7. Additional Terms.

  "Additional permissions" are terms that supplement the terms of this
License by making exceptions from one or more of its conditions.
Additional permissions that are applicable to the entire Program shall
be treated as though they were included in this License, to the extent
that they are valid under applicable law.  If additional permissions
apply only to part of the Program, that part may be used separately
under those permissions, but the entire Program remains governed by
this License without regard to the additional permissions.

  When you convey a copy of a covered work, you may at your option
remove any additional permissions from that copy, or from any part of
it.  (Additional permissions may be written to require their own
removal in certain cases when you modify the work.)  You may place
additional permissions on material, added by you to a covered work,
for which you have or can give appropriate copyright permission.

  Notwithstanding any other provision of this License, for material you
add to a covered work, you may (if authorized by the copyright holders of
that material) supplement the terms of this License with terms:

    a) Disclaiming warranty or limiting liability differently from the
    terms of sections 15 and 16 of this License; or

    b) Requiring preservation of specified reasonable legal notices or
    author attributions in that material or in the Appropriate Legal
    Notices displayed by works containing it; or

    c) Prohibiting misrepresentation of the origin of that material, or
    requiring that modified versions of such material be marked in
    reasonable ways as different from the original version; or

    d) Limiting the use for publicity purposes of names of licensors or
    authors of the material; or

    e) Declining to grant rights under trademark law for use of some
    trade names, trademarks, or service marks; or

    f) Requiring indemnification of licensors and authors of that
    material by anyone who conveys the material (or modified versions of
    it) with contractual assumptions of liability to the recipient, for
    any liability that these contractual assumptions directly impose on
    those licensors and authors.

  All other non-permissive additional terms are considered "further
restrictions" within the meaning of section 10.  If the Program as you
received it, or any part of it, contains a notice stating that it is
governed by this License along with a term that is a further
restriction, you may remove that term.  If a license document contains
a further restriction but permits relicensing or conveying under this
License, you may add to a covered work material governed by the terms
of that license document, provided that the further restriction does
not survive such relicensing or conveying.

  If you add terms to a covered work in accord with this section, you
must place, in the relevant source files, a statement of the
additional terms that apply to those files, or a notice indicating
where to find the applicable terms.

  Additional terms, permissive or non-permissive, may be stated in the
form of a separately written license, or stated as exceptions;
the above requirements apply either way.

  8. Termination.

  You may not propagate or modify a covered work except as expressly
provided under this License.  Any attempt otherwise to propagate or
modify it is void, and will automatically terminate your rights under
this License (including any patent licenses granted under the third
paragraph of section 11).

  However, if you cease all violation of this License, then your
license from a particular copyright holder is reinstated (a)
provisionally, unless and until the copyright holder explicitly and
finally terminates your license, and (b) permanently, if the copyright
holder fails to notify you of the violation by some reasonable means
prior to 60 days after the cessation.

  Moreover, your license from a particular copyright holder is
reinstated permanently if the copyright holder notifies you of the
violation by some reasonable means, this is the first time you have
received notice of violation of this License (for any work) from that
copyright holder, and you cure the violation prior to 30 days after
your receipt of the notice.

  Termination of your rights under this section does not terminate the
licenses of parties who have received copies or rights from you under
this License.  If your rights have been terminated and not permanently
reinstated, you do not qualify to receive new licenses for the same
material under section 10.

  9. Acceptance Not Required for Having Copies.

  You are not required to accept this License in order to receive or
run a copy of the Program.  Ancillary propagation of a covered work
occurring solely as a consequence of using peer-to-peer transmission
to receive a copy likewise does not require acceptance.  However,
nothing other than this License grants you permission to propagate or
modify any covered work.  These actions infringe copyright if you do
not accept this License.  Therefore, by modifying or propagating a
covered work, you indicate your acceptance of this License to do so.

  10. Automatic Licensing of Downstream Recipients.

  Each time you convey a covered work, the recipient automatically
receives a license from the original licensors, to run, modify and
propagate that work, subject to this License.  You are not responsible
for enforcing compliance by third parties with this License.

  An "entity transaction" is a transaction transferring control of an
organization, or substantially all assets of one, or subdividing an
organization, or merging organizations.  If propagation of a covered
work results from an entity transaction, each party to that
transaction who receives a copy of the work also receives whatever
licenses to the work the party's predecessor in interest had or could
give under the previous paragraph, plus a right to possession of the
Corresponding Source of the work from the predecessor in interest, if
the predecessor has it or can get it with reasonable efforts.

  You may not impose any further restrictions on the exercise of the
rights granted or affirmed under this License.  For example, you may
not impose a license fee, royalty, or other charge for exercise of
rights granted under this License, and you may not initiate litigation
(including a cross-claim or counterclaim in a lawsuit) alleging that
any patent claim is infringed by making, using, selling, offering for
sale, or importing the Program or any portion of it.

  11. Patents.

  A "contributor" is a copyright holder who authorizes use under this
License of the Program or a work on which the Program is based.  The
work thus licensed is called the contributor's "contributor version".

  A contributor's "essential patent claims" are all patent claims
owned or controlled by the contributor, whether already acquired or
hereafter acquired, that would be infringed by some manner, permitted
by this License, of making, using, or selling its contributor version,
but do not include claims that would be infringed only as a
consequence of further modification of the contributor version.  For
purposes of this definition, "control" includes the right to grant
patent sublicenses in a manner consistent with the requirements of
this License.

  Each contributor grants you a non-exclusive, worldwide, royalty-free
patent license under the contributor's essential patent claims, to
make, use, sell, offer for sale, import and otherwise run, modify and
propagate the contents of its contributor version.

  In the following three paragraphs, a "patent license" is any express
agreement or commitment, however denominated, not to enforce a patent
(such as an express permission to practice a patent or covenant not to
sue for patent infringement).  To "grant" such a patent license to a
party means to make such an agreement or commitment not to enforce a
patent against the party.

  If you convey a covered work, knowingly relying on a patent license,
and the Corresponding Source of the work is not available for anyone
to copy, free of charge and under the terms of this License, through a
publicly available network server or other readily accessible means,
then you must either (1) cause the Corresponding Source to be so
available, or (2) arrange to deprive yourself of the benefit of the
patent license for this particular work, or (3) arrange, in a manner
consistent with the requirements of this License, to extend the patent
license to downstream recipients.  "Knowingly relying" means you have
actual knowledge that, but for the patent license, your conveying the
covered work in a country, or your recipient's use of the covered work
in a country, would infringe one or more identifiable patents in that
country that you have reason to believe are valid.

  If, pursuant to or in connection with a single transaction or
arrangement, you convey, or propagate by procuring conveyance of, a
covered work, and grant a patent license to some of the parties
receiving the covered work authorizing them to use, propagate, modify
or convey a specific copy of the covered work, then the patent license
you grant is automatically extended to all recipients of the covered
work and works based on it.

  A patent license is "discriminatory" if it does not include within
the scope of its coverage, prohibits the exercise of, or is
conditioned on the non-exercise of one or more of the rights that are
specifically granted under this License.  You may not convey a covered
work if you are a party to an arrangement with a third party that is
in the business of distributing software, under which you make payment
to the third party based on the extent of your activity of conveying
the work, and under which the third party grants, to any of the
parties who would receive the covered work from you, a discriminatory
patent license (a) in connection with copies of the covered work
conveyed by you (or copies made from those copies), or (b) primarily
for and in connection with specific products or compilations that
contain the covered work, unless you entered into that arrangement,
or that patent license was granted, prior to 28 March 2007.

  Nothing in this License shall be construed as excluding or limiting
any implied license or other defenses to infringement that may
otherwise be available to you under applicable patent law.

  12. No Surrender of Others' Freedom.

  If conditions are imposed on you (whether by court order, agreement or
otherwise) that contradict the conditions of this License, they do not
excuse you from the conditions of this License.  If you cannot convey a
covered work so as to satisfy simultaneously your obligations under this
License and any other pertinent obligations, then as a consequence you may
not convey it at all.  For example, if you agree to terms that obligate you
to collect a royalty for further conveying from those to whom you convey
the Program, the only way you could satisfy both those terms and this
License would be to refrain entirely from conveying the Program.

  13. Use with the GNU Affero General Public License.

  Notwithstanding any other provision of this License, you have
permission to link or combine any covered work with a work licensed
under version 3 of the GNU Affero General Public License into a single
combined work, and to convey the resulting work.  The terms of this
License will continue to apply to the part which is the covered work,
but the special requirements of the GNU Affero General Public License,
section 13, concerning interaction through a network will apply to the
combination as such.

  14. Revised Versions of this License.

  The Free Software Foundation may publish revised and/or new versions of
the GNU General Public License from time to time.  Such new versions will
be similar in spirit to the present version, but may differ in detail to
address new problems or concerns.

  Each version is given a distinguishing version number.  If the
Program specifies that a certain numbered version of the GNU General
Public License "or any later version" applies to it, you have the
option of following the terms and conditions either of that numbered
version or of any later version published by the Free Software
Foundation.  If the Program does not specify a version number of the
GNU General Public License, you may choose any version ever published
by the Free Software Foundation.

  If the Program specifies that a proxy can decide which future
versions of the GNU General Public License can be used, that proxy's
public statement of acceptance of a version permanently authorizes you
to choose that version for the Program.

  Later license versions may give you additional or different
permissions.  However, no additional obligations are imposed on any
author or copyright holder as a result of your choosing to follow a
later version.

  15. Disclaimer of Warranty.

  THERE IS NO WARRANTY FOR THE PROGRAM, TO THE EXTENT PERMITTED BY
APPLICABLE LAW.  EXCEPT WHEN OTHERWISE STATED IN WRITING THE COPYRIGHT
HOLDERS AND/OR OTHER PARTIES PROVIDE THE PROGRAM "AS IS" WITHOUT WARRANTY
OF ANY KIND, EITHER EXPRESSED OR IMPLIED, INCLUDING, BUT NOT LIMITED TO,
THE IMPLIED WARRANTIES OF MERCHANTABILITY AND FITNESS FOR A PARTICULAR
PURPOSE.  THE ENTIRE RISK AS TO THE QUALITY AND PERFORMANCE OF THE PROGRAM
IS WITH YOU.  SHOULD THE PROGRAM PROVE DEFECTIVE, YOU ASSUME THE COST OF
ALL NECESSARY SERVICING, REPAIR OR CORRECTION.

  16. Limitation of Liability.

  IN NO EVENT UNLESS REQUIRED BY APPLICABLE LAW OR AGREED TO IN WRITING
WILL ANY COPYRIGHT HOLDER, OR ANY OTHER PARTY WHO MODIFIES AND/OR CONVEYS
THE PROGRAM AS PERMITTED ABOVE, BE LIABLE TO YOU FOR DAMAGES, INCLUDING ANY
GENERAL, SPECIAL, INCIDENTAL OR CONSEQUENTIAL DAMAGES ARISING OUT OF THE
USE OR INABILITY TO USE THE PROGRAM (INCLUDING BUT NOT LIMITED TO LOSS OF
DATA OR DATA BEING RENDERED INACCURATE OR LOSSES SUSTAINED BY YOU OR THIRD
PARTIES OR A FAILURE OF THE PROGRAM TO OPERATE WITH ANY OTHER PROGRAMS),
EVEN IF SUCH HOLDER OR OTHER PARTY HAS BEEN ADVISED OF THE POSSIBILITY OF
SUCH DAMAGES.

  17. Interpretation of Sections 15 and 16.

  If the disclaimer of warranty and limitation of liability provided
above cannot be given local legal effect according to their terms,
reviewing courts shall apply local law that most closely approximates
an absolute waiver of all civil liability in connection with the
Program, unless a warranty or assumption of liability accompanies a
copy of the Program in return for a fee.

                     END OF TERMS AND CONDITIONS

            How to Apply These Terms to Your New Programs

  If you develop a new program, and you want it to be of the greatest
possible use to the public, the best way to achieve this is to make it
free software which everyone can redistribute and change under these terms.

  To do so, attach the following notices to the program.  It is safest
to attach them to the start of each source file to most effectively
state the exclusion of warranty; and each file should have at least
the "copyright" line and a pointer to where the full notice is found.

    <one line to give the program's name and a brief idea of what it does.>
    Copyright (C) <year>  <name of author>

    This program is free software: you can redistribute it and/or modify
    it under the terms of the GNU General Public License as published by
    the Free Software Foundation, either version 3 of the License, or
    (at your option) any later version.

    This program is distributed in the hope that it will be useful,
    but WITHOUT ANY WARRANTY; without even the implied warranty of
    MERCHANTABILITY or FITNESS FOR A PARTICULAR PURPOSE.  See the
    GNU General Public License for more details.

    You should have received a copy of the GNU General Public License
    along with this program.  If not, see <https://www.gnu.org/licenses/>.

Also add information on how to contact you by electronic and paper mail.

  If the program does terminal interaction, make it output a short
notice like this when it starts in an interactive mode:

    <program>  Copyright (C) <year>  <name of author>
    This program comes with ABSOLUTELY NO WARRANTY; for details type `show w'.
    This is free software, and you are welcome to redistribute it
    under certain conditions; type `show c' for details.

The hypothetical commands `show w' and `show c' should show the appropriate
parts of the General Public License.  Of course, your program's commands
might be different; for a GUI interface, you would use an "about box".

  You should also get your employer (if you work as a programmer) or school,
if any, to sign a "copyright disclaimer" for the program, if necessary.
For more information on this, and how to apply and follow the GNU GPL, see
<https://www.gnu.org/licenses/>.

  The GNU General Public License does not permit incorporating your program
into proprietary programs.  If your program is a subroutine library, you
may consider it more useful to permit linking proprietary applications with
the library.  If this is what you want to do, use the GNU Lesser General
Public License instead of this License.  But first, please read
<https://www.gnu.org/licenses/why-not-lgpl.html>.

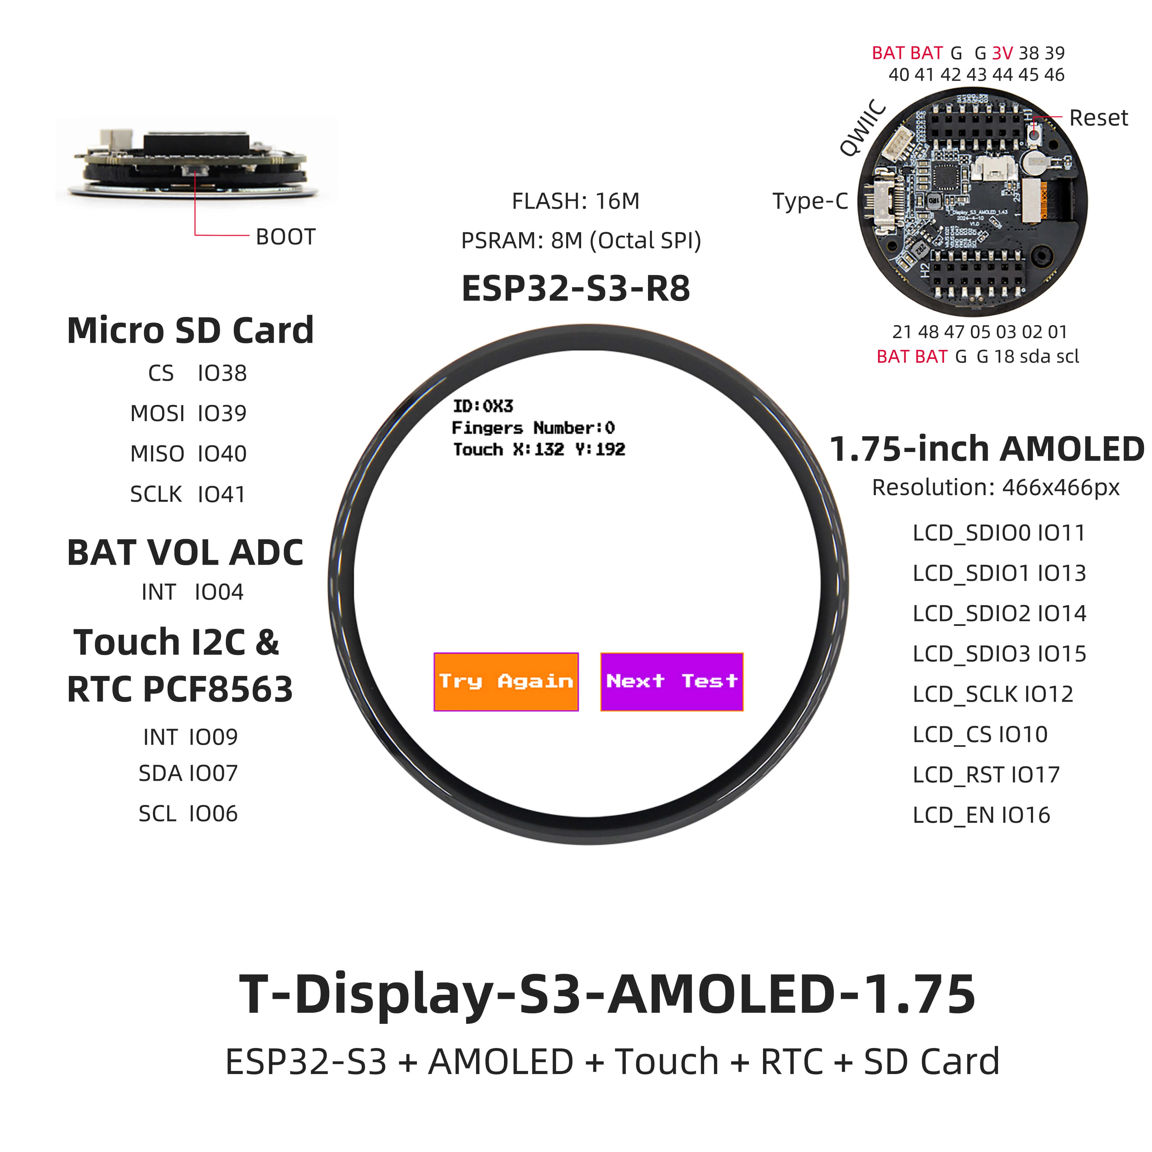
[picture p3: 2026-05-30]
docs/T-Display-S3-AMOLED-1.75-pinmap.jpg

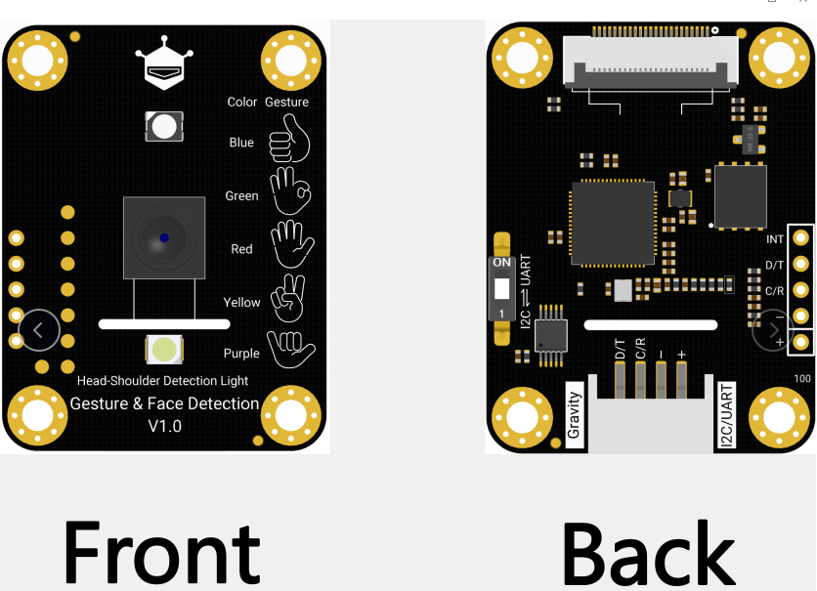
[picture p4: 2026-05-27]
docs/SEN0626/SEN0626svg.png

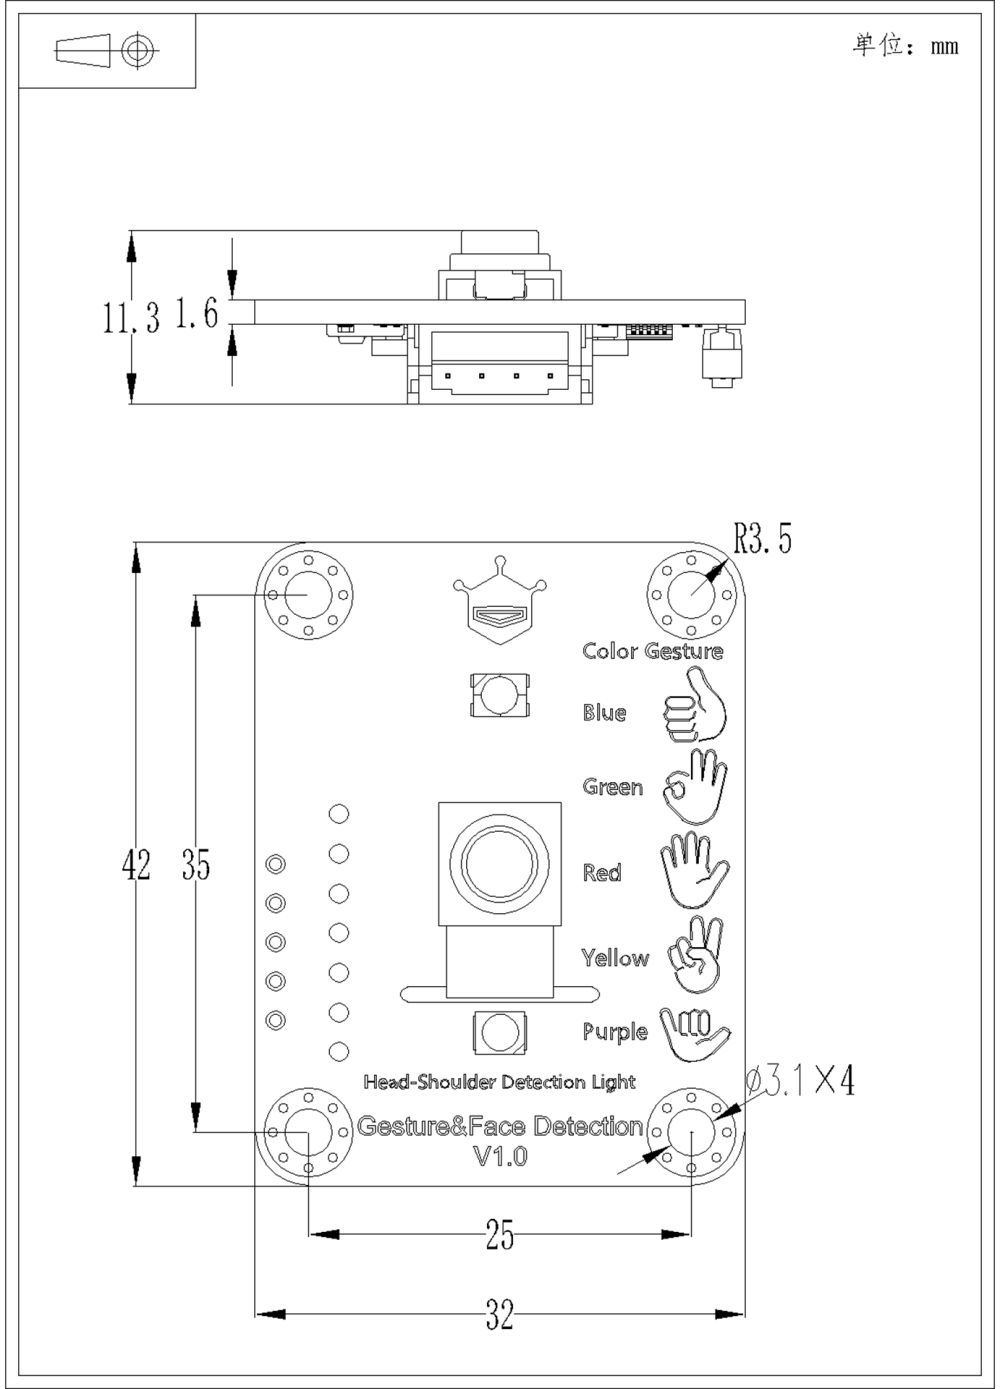
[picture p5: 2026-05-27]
docs/SEN0626/SEN0626_offline-edge-ai-gesture-face-detection-sensor_cad_v1.png

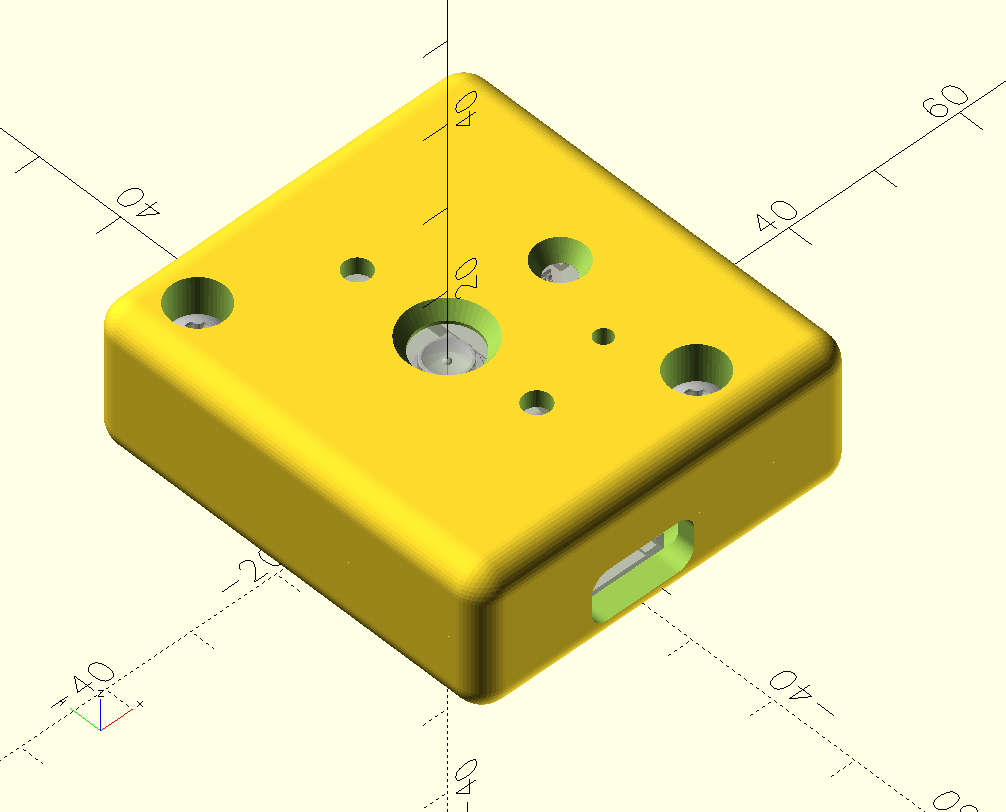
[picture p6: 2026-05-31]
enclosure/Lux and Gesture/Lux and Gesture-2.png

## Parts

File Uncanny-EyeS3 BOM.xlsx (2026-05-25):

Qty | Description | Reference Link | Package Price | Qty | Unit Cost | Total
2 | Lilygo T-Display S3 AMOLED (DS) (H741-02) | https://lilygo.cc/en-us/products/t-display-s3-amoled-1-64?variant=45002266345653 | $30.25 | 1 | $30.25 | $60.50
1 | Adafruit Wii Nunchuck Breakout Adapter (ID:4836) | https://www.adafruit.com/product/4836 | $2.95 | 1 | $2.95 | $2.95
1 | Wii controller (Nunchuck / Wiichuck) (ID:342) | https://www.adafruit.com/product/342 | $12.50 | 1 | $12.50 | $12.50
1 | Gravity: Analog Ambient Light Sensor (DFR0026) | https://www.dfrobot.com/product-1004.html | $2.60 | 1 | $2.60 | $2.60
1 | Gravity: Offline Edge AI Gesture & Face Detection Sensor (SEN0626) | https://www.dfrobot.com/product-2914.html | $14.90 | 1 | $14.90 | $14.90
 |  |  |  |  | Parts Total | $93.45
 |  |  |  |  | 7.634% Tax | $7.13
 |  |  |  |  | Total | $100.58

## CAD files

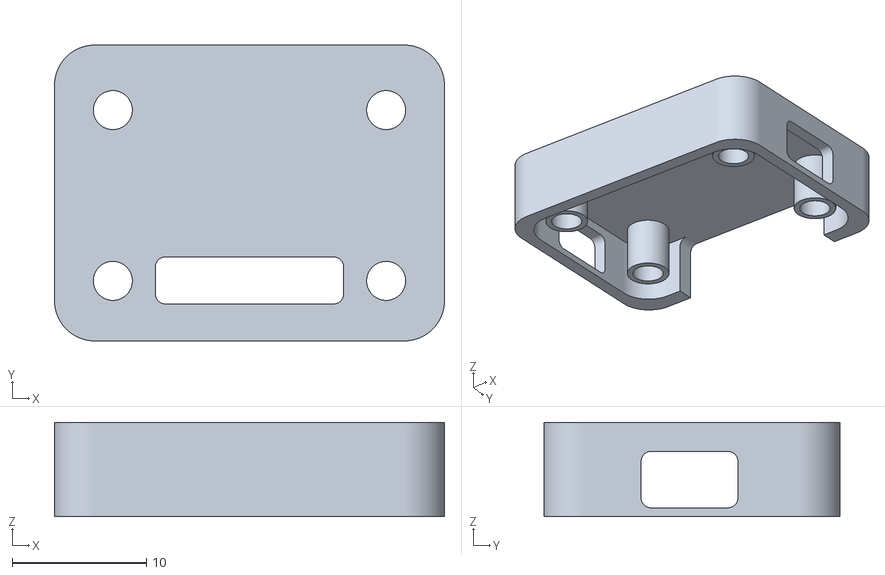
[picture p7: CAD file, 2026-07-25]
enclosure/Adafruit Wii Nunchuck Breakout Adapter/Adafruit Wii Nunchuck Breakout Adapter - top.stl
29.0 x 22.0 x 7.00

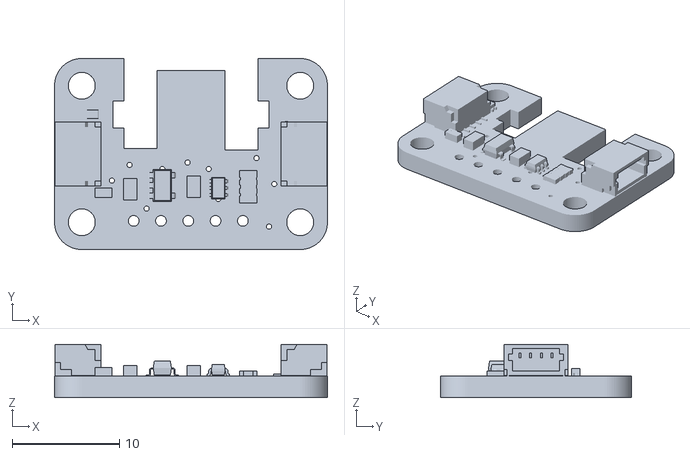
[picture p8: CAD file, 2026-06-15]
enclosure/Adafruit Wii Nunchuck Breakout Adapter/assets/4836-Wii-Nunchuck-Adapter.stl
25.4 x 17.8 x 4.96

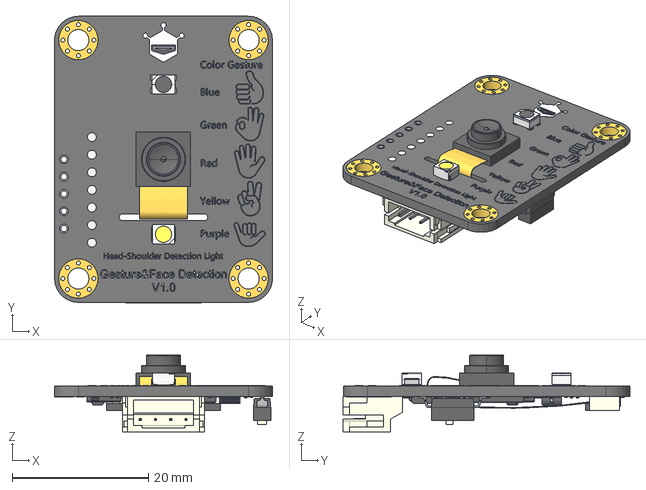
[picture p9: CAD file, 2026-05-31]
enclosure/Lux and Gesture/assets/SEN0626_3D_STP.stp
32.0 x 42.1 x 11.3 mm

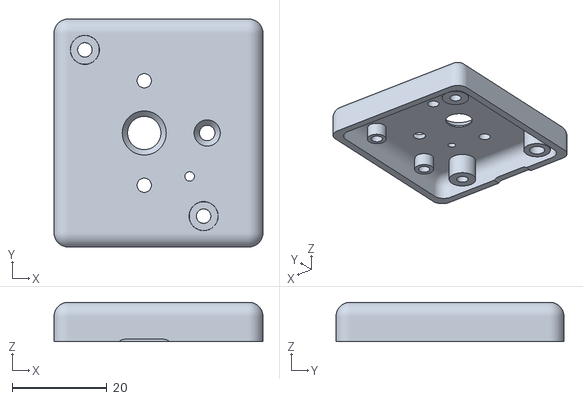
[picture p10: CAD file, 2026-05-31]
enclosure/Lux and Gesture/Lux and Gesture - top.stl
44.0 x 48.0 x 8.32

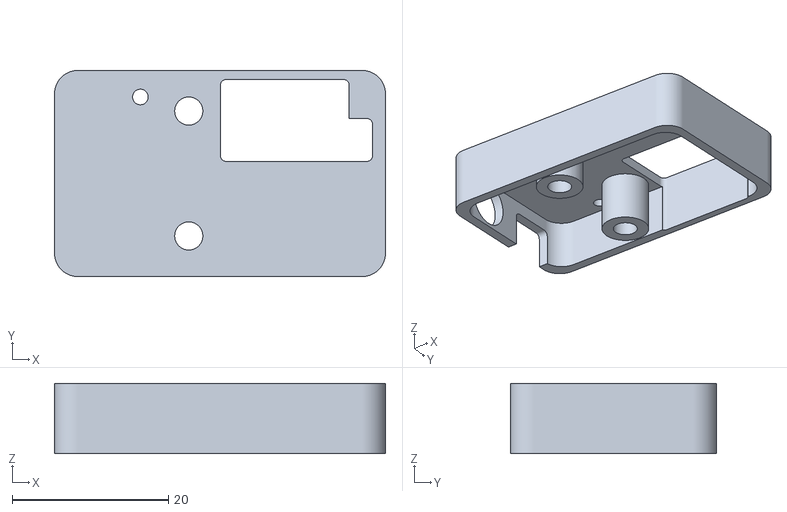
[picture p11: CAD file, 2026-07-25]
enclosure/Servo Power Supply Board/Servo Power Supply Board - top.stl
42.4 x 26.4 x 9.00

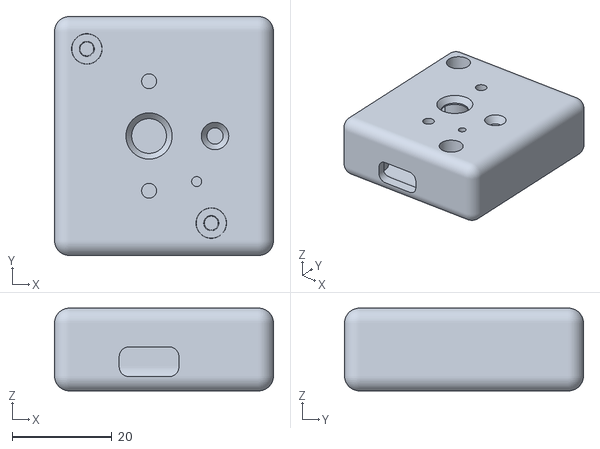
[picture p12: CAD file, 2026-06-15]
enclosure/T-Display-AMOLED-1.75/assets/Lux and Gesture.stl
44.0 x 48.0 x 16.6

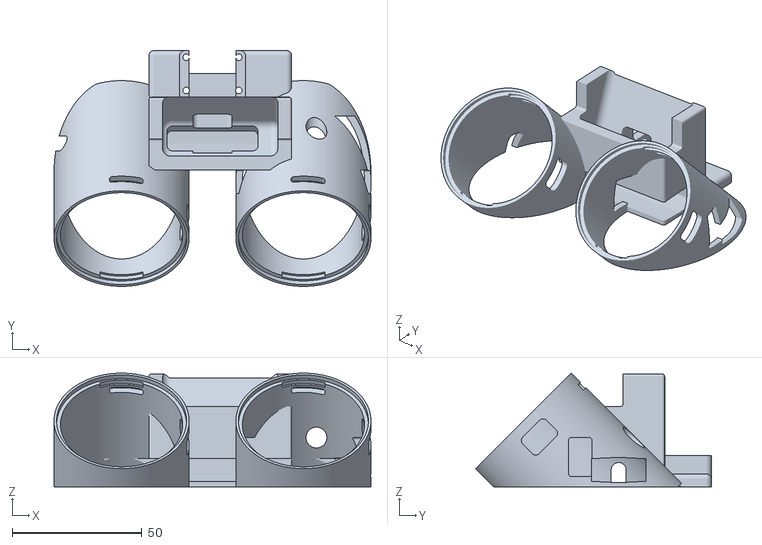
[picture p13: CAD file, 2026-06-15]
enclosure/T-Display-AMOLED-1.75/T-Display-AMOLED-1.75.stl
122.0 x 90.7 x 43.8

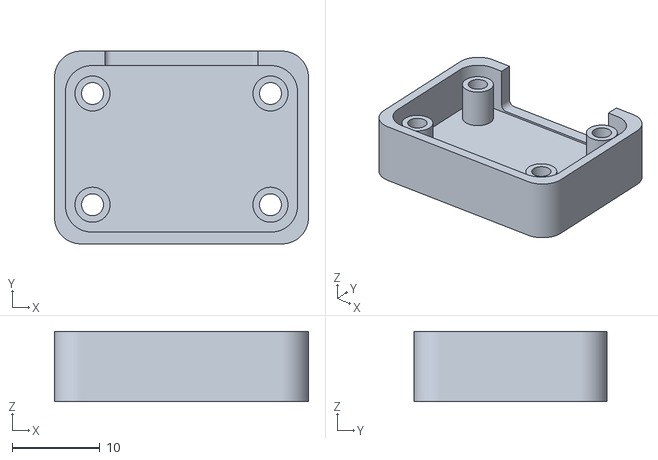
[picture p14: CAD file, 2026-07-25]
enclosure/Adafruit Wii Nunchuck Breakout Adapter/Adafruit Wii Nunchuck Breakout Adapter - bottom.stl
29.0 x 22.0 x 8.00

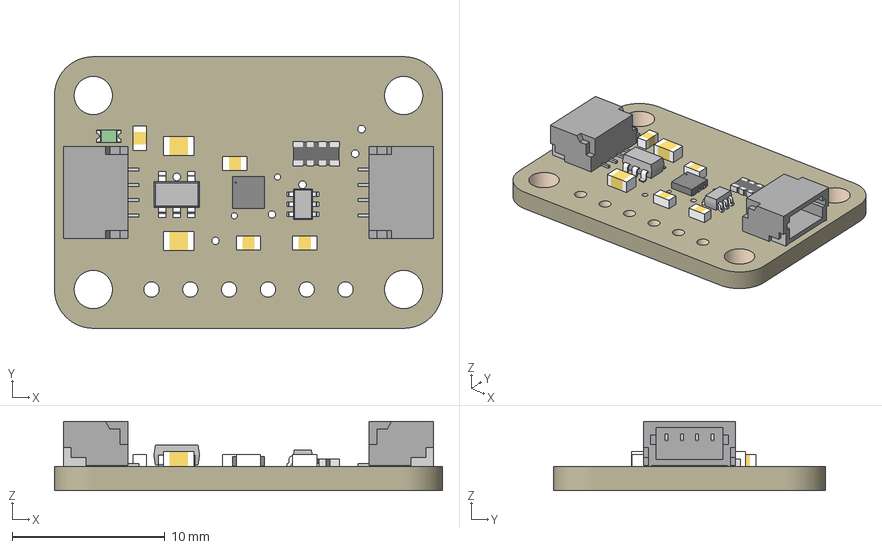
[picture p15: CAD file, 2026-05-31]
enclosure/Lux and Gesture/assets/6498 MAX44009 Light Sensor.3mf
25.4 x 17.8 x 4.53 mm
Board

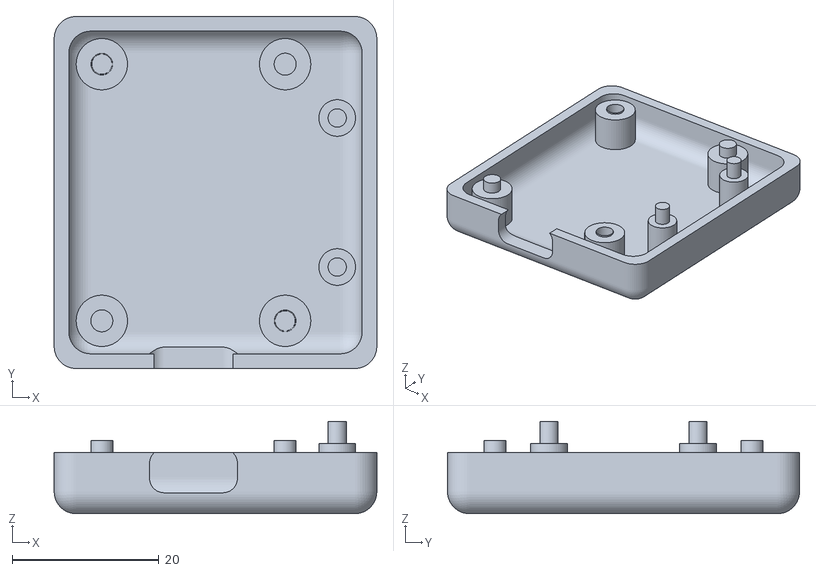
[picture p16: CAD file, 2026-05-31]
enclosure/Lux and Gesture/Lux and Gesture - bottom.stl
44.0 x 48.0 x 12.6

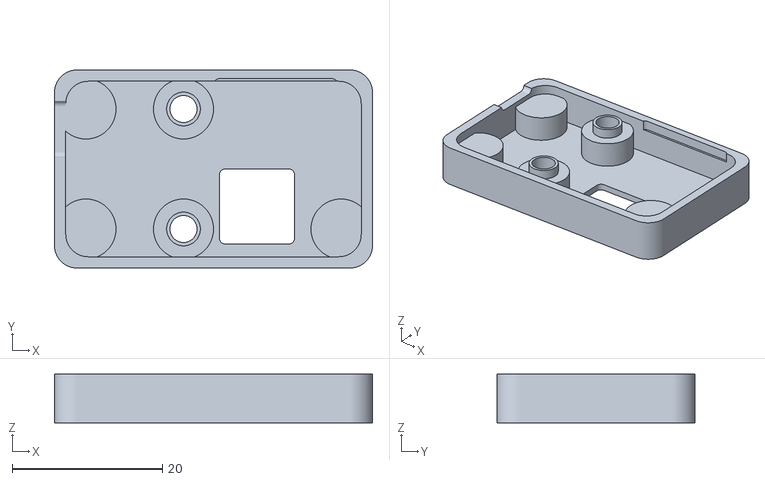
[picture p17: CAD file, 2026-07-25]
enclosure/Servo Power Supply Board/Servo Power Supply Board - bottom.stl
42.4 x 26.4 x 6.50

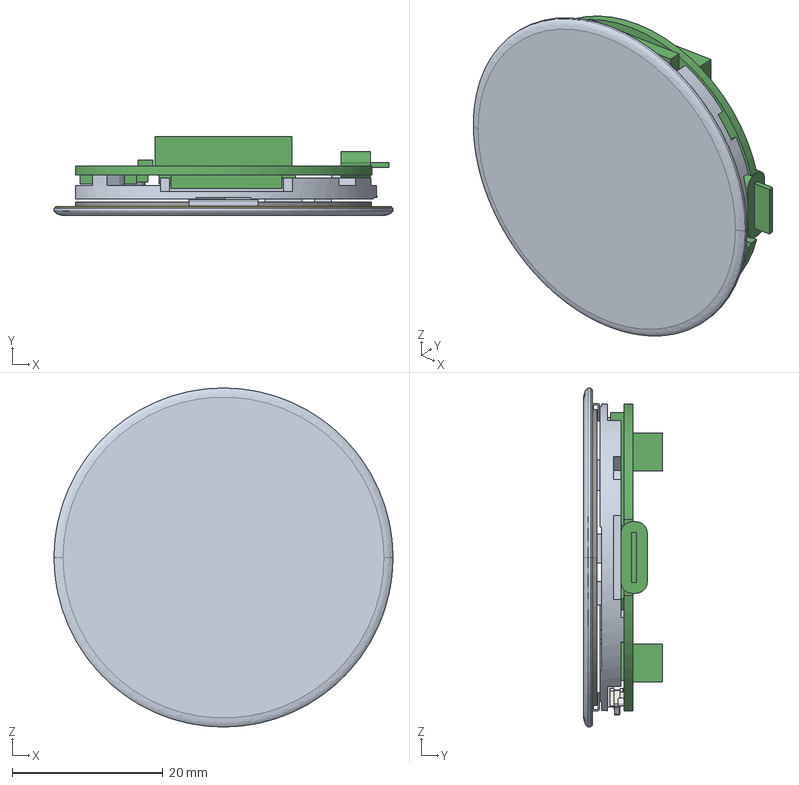
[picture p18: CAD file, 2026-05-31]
enclosure/T-Display-AMOLED-1.75/assets/H741-1.stp
45.0 x 10.4 x 45.0 mm
WIFI
PCB

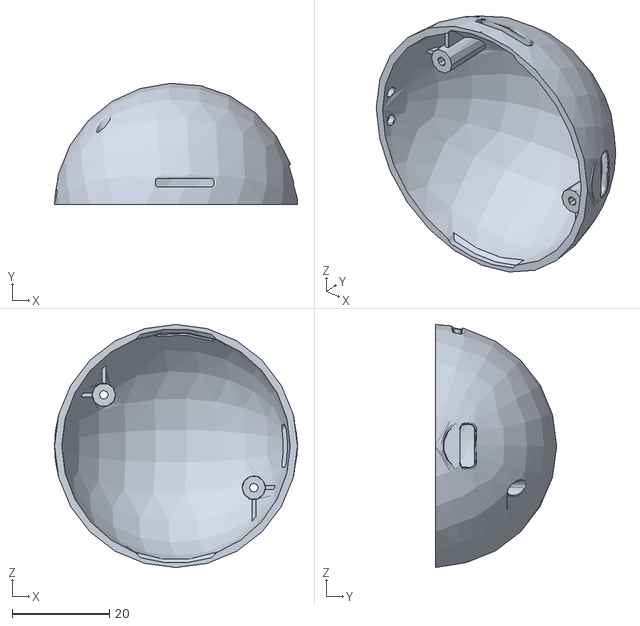
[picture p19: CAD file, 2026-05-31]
enclosure/T-Display-AMOLED-1.75/assets/Transparent Shell.stl
50.0 x 25.0 x 50.0

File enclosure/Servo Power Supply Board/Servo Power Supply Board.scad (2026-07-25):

// // // //
// INCLUDES
// // // //

// https://github.com/BelfrySCAD/BOSL2
include <BOSL2/std.scad>
include <BOSL2/screws.scad>
include <BOSL2/threading.scad>


// // // //
// PARAMETERS
// // // //

// Minimum angle for a fragment. The default value is 12 (i.e. 30 fragments
// for a full circle). The minimum allowed value is 0.01.
$fa = $preview ? 5 : 1;
// Minimum size of a fragment. The default value is 2 so very small circles
// have a smaller number of fragments than specified using $fa. The minimum
// allowed value is 0.01.
$fs = $preview ? 1 : 0.1;
// Number of fragments in a full circle. When this variable has a value
// greater than zero, the other two variables are ignored, and a full circle
// is rendered using this number of fragments.
$fn = 0;


// // // //
// FUNCTIONS
// // // //

// Two formulas have been identified for modifying the dimensions of
// hole diameters. To use these formulas, the x value is your desired
// diameter (for example 4 mm) and the y value is the adjusted diameter
// for your CAD model (in this case 4.34 mm). Use the vertical hole
// formula if the axis of the hole is parallel with the Z axis of the
// build plate and the horizontal hole formula if the axis of the hole
// is parallel with the X or Y axes. Both of these formulas are in
// millimeters.
//   y = 1.0155x + 0.2795 vertical
//   y = 0.9927x + 0.3602 horizontal
function dah(diameter, vertical = true) = vertical == true ? (1.0155 * diameter) + 0.2795 : (0.9927 * diameter) + 0.3602;


// // // //
// MODULES
// // // //

module fillet(r, h) {
    translate([r / 2, r / 2, 0]) {
        difference() {
            cube([r + 0.01, r + 0.01, h], center = true);

            translate([r / 2, r / 2, 0])
                cylinder(r = r, h = h + 1, center = true);

        }
    }
}

module hsi(d, h) {
    union() {
        translate([0, 0, -(1.8 * h + 1) / 2 + 1])
            cylinder(d = dah(d), h = 1.8 * h + 1, center = true);

        cylinder(d1 = dah(d), d2 = dah(d) + 2, h = 2, center = true);
    }
}

// https://www.thingiverse.com/thing:6769037/files
module torus(d = 10, thickness = 4, res = 20) {
    rotate_extrude($fn = res) {
        translate([d, 0]) circle(thickness, $fn = res);
    }
}


// // // //
// MAIN
// // // //

difference() {
    union() {
        difference() {
            union() {
                difference() {
                    translate([0, 0, 9 / 2 + 1.5])
                        cuboid([38.4 + 1 + 3, 22.4 + 1 + 3, 9], rounding = 3, except = [TOP,BOTTOM]);

                    // interior cut
                    translate([0, 0, 9 / 2])
                        cuboid([38.4 + 1, 22.4 + 1, 9], rounding = 3, except = [TOP,BOTTOM]);
                }

                // screw posts
                translate([-4, 0, 0]) {
                    translate([0, 0, 9 / 2 + 1.5]) {
                        translate([0, -16 / 2, 0])
                            cylinder(d = 7, h = 9, center = true);
                        translate([0, 16 / 2, 0])
                            cylinder(d = 7, h = 9, center = true);
                    }
                }
            }
        }

        union() {
            difference() {
                translate([0, 0, -6.5 / 2 + 1.5])
                    cuboid([38.4 + 1 + 3, 22.4 + 1 + 3, 6.5], rounding = 3, except = [TOP,BOTTOM]);

                // interior cut
                translate([0, 0, 0])
                    cuboid([38.4 + 1, 22.4 + 1, 5 + 3], rounding = 3, except = [TOP,BOTTOM]);

                // heat sink cut
                #translate([5.8, -5, -5.5 / 2])
                    cuboid([10, 10, 5.5], rounding = 0.75, except = [TOP,BOTTOM]);

            }

            // screw posts
            translate([-4, 0, 0]) {
                translate([0, 0, -6.5 / 2 + 1.5]) {
                    translate([0, -16 / 2, 0])
                        cylinder(d = 4.5, h = 6.5, center = true);
                    translate([0, 16 / 2, 0])
                        cylinder(d = 4.5, h = 6.5, center = true);
                }

                translate([0, 0, -5 / 2]) {
                    translate([0, -16 / 2, 0])
                        cylinder(d = 8, h = 5, center = true);
                    translate([0, 16 / 2, 0])
                        cylinder(d = 8, h = 5, center = true);
                }
                #translate([-13, 0, -5 / 2]) {
                    translate([0, -16 / 2, 0])
                        cylinder(d = 8, h = 5, center = true);
                    translate([0, 16 / 2, 0])
                        cylinder(d = 8, h = 5, center = true);
                }
                #translate([21, 0, -5 / 2]) {
                    translate([0, -16 / 2, 0])
                        cylinder(d = 8, h = 5, center = true);
                    *translate([0, 16 / 2, 0])
                        cylinder(d = 8, h = 5, center = true);
                }
            }
        }
    }

    // power LED cut
    #translate([-10.2, 9.8, 50 / 2])
        cylinder(d = 2, h = 50, center = true);

    // 2.54mm header cut
    #translate([9.8, 6.8, 50 / 2]) {
        translate([-1.5, 5 / 2, 0])
            cuboid([16 + 0.5, 5 + 0.5, 50], rounding = 0.75, except = [TOP,BOTTOM]);
        translate([0, -5 / 2, 0])
            cuboid([19 + 0.5, 5 + 0.5, 50], rounding = 0.75, except = [TOP,BOTTOM]);
        #translate([-8.75, 0, 0])
            cube([2, 5, 50], center = true);
    }

    // PH2.0 connector cut
    #translate([-19.2, 5.3, (6 + 0.25) / 2 + 0.75])
        cuboid([15, 7 + 0.5, 6 + 0.25], rounding = 0.75, except = [LEFT,RIGHT]);

    // 2.1mm barrel connector cut
    #translate([-15 / 2 - 19.7, -5.2, 5.5])
        rotate([0, 90, 0])
            cylinder(d = 7, h = 15, center = true);

    // screw hole cut
    #translate([-4, 0, 0]) {
        translate([0, -16 / 2, 0]) {
            cylinder(d = 3.6, h = 50, center = true);
            rotate([0, 0, 0])
                %screw("M3", head="socket", length = 18, anchor = "head_bot");
            translate([0, 0, -10 / 2 + 2.5])
                rotate([180, 0, 0])
                    nut_trap_inline(10, "M3", $slop = 0.1);
        }
        translate([0, 16 / 2, 0]) {
            cylinder(d = 3.6, h = 50, center = true);
            rotate([0, 0, 0])
                %screw("M3", head="socket", length = 18, anchor = "head_bot");
            translate([0, 0, -10 / 2 + 2.5])
                rotate([180, 0, 0])
                    nut_trap_inline(10, "M3", $slop = 0.1);
        }
    }
}

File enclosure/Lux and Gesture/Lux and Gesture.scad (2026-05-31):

// // // //
// INCLUDES
// // // //

// https://github.com/BelfrySCAD/BOSL2
include <BOSL2/std.scad>
include <BOSL2/screws.scad>
include <BOSL2/threading.scad>


// // // //
// PARAMETERS
// // // //

// Minimum angle for a fragment. The default value is 12 (i.e. 30 fragments
// for a full circle). The minimum allowed value is 0.01.
$fa = $preview ? 5 : 1;
// Minimum size of a fragment. The default value is 2 so very small circles
// have a smaller number of fragments than specified using $fa. The minimum
// allowed value is 0.01.
$fs = $preview ? 1 : 0.1;
// Number of fragments in a full circle. When this variable has a value
// greater than zero, the other two variables are ignored, and a full circle
// is rendered using this number of fragments.
$fn = 50;


// // // //
// FUNCTIONS
// // // //

// Two formulas have been identified for modifying the dimensions of
// hole diameters. To use these formulas, the x value is your desired
// diameter (for example 4 mm) and the y value is the adjusted diameter
// for your CAD model (in this case 4.34 mm). Use the vertical hole
// formula if the axis of the hole is parallel with the Z axis of the
// build plate and the horizontal hole formula if the axis of the hole
// is parallel with the X or Y axes. Both of these formulas are in
// millimeters.
//   y = 1.0155x + 0.2795 vertical
//   y = 0.9927x + 0.3602 horizontal
function dah(diameter, vertical = true) = vertical == true ? (1.0155 * diameter) + 0.2795 : (0.9927 * diameter) + 0.3602;

/**
 * @brief Generate a cylinder with a 1° slope.
 *
 * @param d Diameter of cylinder.
 * @param h Height of cylinder.
**/
function d1deg(d, h) = d + (2 * h * tan(1));


// // // //
// MODULES
// // // //

module fillet(r, h) {
    translate([r / 2, r / 2, 0]) {
        difference() {
            cube([r + 0.01, r + 0.01, h], center = true);

            translate([r / 2, r / 2, 0])
                cylinder(r = r, h = h + 1, center = true);

        }
    }
}

module hsi(d, h) {
    union() {
        translate([0, 0, -(1.8 * h + 1) / 2 + 1])
            cylinder(d = dah(d), h = 1.8 * h + 1, center = true);

        cylinder(d1 = dah(d), d2 = dah(d) + 2, h = 2, center = true);
    }
}

// https://www.thingiverse.com/thing:6769037/files
module torus(d = 10, thickness = 4, res = 20) {
    rotate_extrude($fn = res) {
        translate([d, 0]) circle(thickness, $fn = res);
    }
}

module Adafruit_6498() {
    translate([8.89, -12.7, 0])
        rotate([0, 0, 90])
            import("assets/6498 MAX44009 Light Sensor.3mf");

    // reference center        
    *#cylinder(h = 50, d = 1, center = true);
}

module SEN0626() {
    translate([-375, -330, -15.30106])
        rotate([0, 0, 0])
            import("assets/SEN0626_3D_STP.stl");

    // reference center        
    *#cylinder(h = 50, d = 1, center = true);
}


// // // //
// MAIN
// // // //

$top = 1;
$bottom = 1;

$internal_x = 40;
$internal_y = 44;
$internal_z = 12.63;
$wall_thk = 2;
$exterior_rounding_r = 3;

adafruit_thick = 1.70; 
sen0626_thick  = 1.05;

difference() {
    union() {
        if($top)
        difference() {
            union() {
                translate([3, 0, ($internal_z / 2 + $wall_thk) / 2 + $internal_z / 2]) {
                    difference() {
                            cuboid([$internal_x + $wall_thk * 2, $internal_y + $wall_thk * 2, $internal_z / 2 + $wall_thk], rounding = $exterior_rounding_r, except = [BOTTOM]);

                            // interior cut
                            translate([0, 0, -$wall_thk])
                                cuboid([$internal_x, $internal_y, $internal_z / 2 + $wall_thk], rounding = $exterior_rounding_r, except = [BOTTOM]);
                    }
                }

                translate([13.25, 0, 7.6]) {
                    %Adafruit_6498();

                    translate([6.35, 0, adafruit_thick]) {
                        difference() {
                            translate([0, 0, 4 / 2])
                                ycopies(spacing = 20.32, n = 2)
                                    cylinder(d = 5, h = 4, center = true);
                            translate([0, 0, -3 / 2 + 2])
                                ycopies(spacing = 20.32, n = 2)
                                cylinder(d = 3, h = 3, center = true);
                        }
                    }
                }

                translate([0, 0, 6]) {
                    %SEN0626();

                    difference() {
                        translate([0, 0, sen0626_thick]) {
                            translate([0, 0, 6.2 / 2])
                                grid_copies(spacing = [25, 35], n = [2, 2])
                                    cylinder(d = 7, h = 6.2, center = true);
                        }

                        translate([0, 0, sen0626_thick]) {
                            translate([-25 / 2, -35 / 2, 0])
                                cylinder(d = 4, h = 6.2, center = true);
                            translate([25 / 2, 35 / 2, 0])
                                cylinder(d = 8, h = 11.2, center = true);
                        }
                    }
                }
            }
        }

        if($bottom)
        difference() {
            union() {
                translate([3, 0, ($internal_z / 2 + $wall_thk) / 2 - $wall_thk]) {
                    difference() {
                            cuboid([$internal_x + $wall_thk * 2, $internal_y + $wall_thk * 2, $internal_z / 2 + $wall_thk], rounding = $exterior_rounding_r, except = [TOP]);

                            // interior cut
                            translate([0, 0, $wall_thk])
                                cuboid([$internal_x, $internal_y, $internal_z / 2 + $wall_thk], rounding = $exterior_rounding_r, except = [TOP]);
                    }
                }

                translate([13.25, 0, 7.6]) {
                    %Adafruit_6498();

                    translate([6.35, 0, 0]) {
                        translate([0, 0, -7.6 / 2])
                            ycopies(spacing = 20.32, n = 2)
                                cylinder(d = 5, h = 7.6, center = true);
                        translate([0, 0, -10.6 / 2 + 3])
                            ycopies(spacing = 20.32, n = 2)
                            cylinder(d = 2.5, h = 10.6, center = true);
                    }
                }

                translate([0, 0, 6]) {
                    %SEN0626();
                    
                    translate([0, 0, 0]) {
                        translate([0, 0, -6 / 2])
                            grid_copies(spacing = [25, 35], n = [2, 2])
                                cylinder(d = 7, h = 6, center = true);
                        translate([0, 0, -8 / 2 + 2])
                            grid_copies(spacing = [25, 35], n = [2, 2])
                                cylinder(d = 3, h = 8, center = true);
                    }
                }
            }
        }
    }

    // case screws
    translate([0, 0, 6 + sen0626_thick + $wall_thk]) {
        translate([25 / 2, -35 / 2, 0]) {
            translate([0, 0, -14 / 2 + 3])
                cylinder(d1 = 3.1 * 2 - d1deg(3.1, 11), d2 = 3.2, h = 14, center = true);
            translate([0, 0, 50 / 2])
                cylinder(d1 = 6, d2 = d1deg(6, 50), h = 50, center = true);
            if ($top)
            %screw("M3x1", head = "pan", drive = "phillips", length = 10, anchor = "head_bot");
        }
        translate([-25 / 2, 35 / 2, 0]) {
            translate([0, 0, -14 / 2 + 3])
                cylinder(d1 = 3.1 * 2 - d1deg(3.1, 11), d2 = 3.2, h = 14, center = true);
            translate([0, 0, 50 / 2])
                cylinder(d1 = 6, d2 = d1deg(6, 50), h = 50, center = true);
            if ($top)
            %screw("M3x1", head = "pan", drive = "phillips", length = 10, anchor = "head_bot");
        }
    }

    //Adafruit_6498
    translate([13.25, -0, 24.15]) {
        cylinder(d = 3.25, h = 30, center = true);
        translate([0, 0, -9])
            cylinder(d1 = 3.25, d2 = 9, h = 5, center = true);
    }
    translate([9.56, -9.15, 24.15])
        cylinder(d = 2, h = 30, center = true);

    // SEN0626
    translate([0, -$internal_y / 2, 3.85])
        cuboid([12, 20, 6], rounding = 2, except = [FRONT,BACK]);
    translate([0, 0, 24.5]) {
        cylinder(d = 7, h = 30, center = true);
        translate([0, 0, -9])
            cylinder(d1 = 7, d2 = 14, h = 5, center = true);
    }
    translate([0, 11, 24.5])
        cylinder(d = 3, h = 30, center = true);
    translate([0, -11, 24.5])
        cylinder(d = 3, h = 30, center = true);

    // temp cuts
    *translate([100 / 2 + 13, 0, 0]) {
        cube([100, 100, 50], center = true);
    }
}

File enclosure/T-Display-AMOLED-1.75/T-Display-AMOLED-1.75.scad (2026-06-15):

// // // //
// INCLUDES
// // // //

// https://github.com/BelfrySCAD/BOSL2
include <BOSL2/std.scad>
include <BOSL2/screws.scad>
include <BOSL2/threading.scad>


// // // //
// PARAMETERS
// // // //

// Minimum angle for a fragment. The default value is 12 (i.e. 30 fragments
// for a full circle). The minimum allowed value is 0.01.
$fa = $preview ? 5 : 1;
// Minimum size of a fragment. The default value is 2 so very small circles
// have a smaller number of fragments than specified using $fa. The minimum
// allowed value is 0.01.
$fs = $preview ? 1 : 0.1;
// Number of fragments in a full circle. When this variable has a value
// greater than zero, the other two variables are ignored, and a full circle
// is rendered using this number of fragments.
$fn = 0;


// // // //
// FUNCTIONS
// // // //

// Two formulas have been identified for modifying the dimensions of
// hole diameters. To use these formulas, the x value is your desired
// diameter (for example 4 mm) and the y value is the adjusted diameter
// for your CAD model (in this case 4.34 mm). Use the vertical hole
// formula if the axis of the hole is parallel with the Z axis of the
// build plate and the horizontal hole formula if the axis of the hole
// is parallel with the X or Y axes. Both of these formulas are in
// millimeters.
//   y = 1.0155x + 0.2795 vertical
//   y = 0.9927x + 0.3602 horizontal
function dah(diameter, vertical = true) = vertical == true ? (1.0155 * diameter) + 0.2795 : (0.9927 * diameter) + 0.3602;


// // // //
// MODULES
// // // //

module fillet(r, h) {
    translate([r / 2, r / 2, 0]) {
        difference() {
            cube([r + 0.01, r + 0.01, h], center = true);

            translate([r / 2, r / 2, 0])
                cylinder(r = r, h = h + 1, center = true);

        }
    }
}

module hsi(d, h) {
    union() {
        translate([0, 0, -(1.8 * h + 1) / 2 + 1])
            cylinder(d = dah(d), h = 1.8 * h + 1, center = true);

        cylinder(d1 = dah(d), d2 = dah(d) + 2, h = 2, center = true);
    }
}

module Adafruit_4836() {
    translate([0, 0, 0])
        rotate([0, 0, 0])
            import("assets/4836-Wii-Nunchuck-Adapter.stl");

    // reference center        
    *#cylinder(h = 50, d = 1, center = true);
}

module B0C2YN8F7Z() {
    translate([0, 0, 0]) {
        rotate([0, 0, 90]) {
            width  = 21;
            length = 103;
            h_edge = 8.75;
            h_ctr  = 9.75;

            // Total thickness variance is 1mm, split evenly between top and bottom sides
            side_drop = (h_ctr - h_edge) / 2; // 0.5 mm drop per side

            // Calculate the radius of the crowning cylinders using the sagitta formula
            crown_radius = (pow(width, 2) / (8 * side_drop)) + (side_drop / 2);

            $fn = 64; // Smooth curve resolution

            intersection() {
                // 1. Base shape: Extruded rounded rectangle centered on the Z-axis
                linear_extrude(height = h_ctr, center = true) {
                    rect(size=[width, length], rounding=0);
                }
                
                // 2. Top Crowning Cylinder
                // Shifted down so its lower edge cuts the top curve
                translate([0, 0, (h_ctr/2) - crown_radius])
                    ycyl(r = crown_radius, l = length + 2);
                    
                // 3. Bottom Crowning Cylinder
                // Shifted up so its upper edge cuts the bottom curve
                translate([0, 0, -(h_ctr/2) + crown_radius])
                    ycyl(r = crown_radius, l = length + 2);
            }
        }

        translate([34.75 - 103 / 2, -(20.5 + 9) / 2, (15 - 9) / 2 + 2]) {
            *translate([17 * 0, 0, 0])
                cuboid([13, 9, 15], rounding = 1, except = [FRONT,BACK]);
            translate([17 * 1, 0, 0])
                cuboid([13, 9, 15], rounding = 1, except = [FRONT,BACK]);
            translate([17 * 2, 0, 0])
                cuboid([13, 9, 15], rounding = 1, except = [FRONT,BACK]);
            translate([17 * 3, 0, 0])
                cuboid([13, 9, 15], rounding = 1, except = [FRONT,BACK]);

            translate([103 / 2 + 17, 0, 0])
                cuboid([103, 9, 15], rounding = 1);
        }

        hull() {
            translate([-103 / 2 - 50 / 2 + 1, 0, 0])
                rotate([0, 90, 0])
                    cylinder(d = 5.75, h = 50, center = true);

            translate([-103 / 2 - 50 / 2 + 1, 0, -20])
                rotate([0, 90, 0])
                    cylinder(d = 5.75, h = 50, center = true);
        }
    }
}

module H741_1() {
    translate([-125.3, -114.2, 0])
        rotate([0, 0, 0])
            import("assets/H741-1.stl");

    // reference center        
    *#cylinder(h = 50, d = 1, center = true);
}

module shell() {
    translate([0, 0, 0])
        rotate([-90, 0, 0])
            %import("assets/Transparent Shell.stl");

    *translate([0, 0, -11.8]) {
        difference() {
            union() {
                translate([-14.85, 10.52, 0])
                    cylinder(d = 5, h = 10, center = true);
                translate([16.02, -8.57, 0])
                    cylinder(d = 5, h = 10, center = true);
            }

            translate([0, 0, 0]) {
                translate([-14.85, 10.52, 0])
                    cylinder(d = 2, h = 50, center = true);
                translate([16.02, -8.57, 0])
                    cylinder(d = 2, h = 50, center = true);
            }
        }
    }

    translate([0, 0, -5]) {
        difference() {
            union() {
                translate([0, 0, -50 / 2])
                    cylinder(d = 50, h = 60, center = true);

                translate([0, 0, 2]) {
                    difference() {
                        translate([0, 0, -50 / 2])
                            cylinder(d = 52, h = 60, center = true);

                        translate([0, 0, -50 / 2])
                            cylinder(d = 50, h = 62, center = true);
                    }
                }
            }

            translate([0, 0, 0]) {
                cylinder(d = 47, h = 100, center = true);
            }

            translate([0, 0, 4.6]) {
                intersection() {
                    cube([16.5, 50, 3], center = true);

                    cylinder(d = 48.5, h = 3, center = true);
                }
            }

            // USB port
            translate([50 / 2, 0, -1.75])
                cuboid([30, 13, 9], rounding = 2);

            // micro SD
            translate([1.8, 50 / 2, 0.5])
                cuboid([13, 30, 3], rounding = 1);
        }
    }
    
    // reference center        
    *#cylinder(h = 50, d = 1, center = true);
}


// https://www.thingiverse.com/thing:6769037/files
module torus(d = 10, thickness = 4, res = 20) {
    rotate_extrude($fn = res) {
        translate([d, 0]) circle(thickness, $fn = res);
    }
}


// // // //
// MAIN
// // // //

difference() {
    union() {
        difference() {
            translate([3, 39, -3])
                cuboid([55, 28, 45], rounding = 1);

            translate([0, 49, 15])
                rotate([70, 0, 0])
                    %import("assets/Lux and Gesture.stl");

            translate([3, 37 - 27 / 2, 32])
                cuboid([60, 27, 50], rounding = 1);
        }

        translate([0, 0, 0]) {
            rotate([45, 0, 0]) {
                translate([-35, 0, 0])
                    shell();
                translate([35, 0, 0])
                    shell();
            }
        }

        translate([0, 65.7, -12]) {
            %Adafruit_4836();
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

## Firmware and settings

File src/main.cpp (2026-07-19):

/**
 * @file main.cpp
 * @brief Main entry point for the Uncanny Eyes ESP32 firmware.
 *
 * Initializes display, power management (SY6970), input devices
 * (WiiChuck, LightSensor, GestureFaceInput), and network (ESP-NOW). Runs the eye
 * animation at ~120 FPS on a dedicated FreeRTOS task pinned to
 * Core 1, with a lightweight status loop on loop().
 *
 * Supported boards:
 * - LilyGo T-Display S3 AMOLED (CO5300 via QSPI)
 * - LilyGo T-RGB (ST7701S via DPI)
 */
#include <Arduino.h>
#include <Arduino_DriveBus_Library.h>
#include "common/EyeState.h"
#include "eye/EyeConfig.h"
#include "common/DisplayGeometry.h"
#include "common/DisplayHAL.h"
#include "display/AMOLEDDisplay.h"
#include "display/TRGBDisplay.h"
#include "eye/EyeAnimator.h"
#include "input/WiiChuck.h"
#include "input/LightSensor.h"
#include "input/LuxSensor.h"
#include "input/GestureFaceInput.h"
#include "network/EyeSync.h"
#include "config/SDConfig.h"
#include "debug/DebugOverlay.h"
#include "eyes.h"
#include "EyeLibrary.h"
#include "BoardPins.h"
#include <Wire.h>
#include <esp_wifi.h>
#include "driver/i2c_master.h"
#include <esp_heap_caps.h>

// #define DEBUG_FPS_ENABLED           // Comment out to suppress FPS diagnostic messages on serial
// #define DEBUG_TIMING_ENABLED        // Comment out to suppress timing diagnostic messages on serial
// #define PCF85063_DIAGNOSTIC_ENABLED // Comment out to suppress PCF85063 diagnostic status output on serial
// #define SY6970_DIAGNOSTIC_ENABLED   // Comment out to suppress SY6970 diagnostic status output on serial

#if defined(DEBUG_FPS_ENABLED)
static uint32_t s_frameCount = 0;
static uint32_t s_fpsTimer = 0;
static uint32_t s_currentFps = 0;
#endif

static DeviceConfig s_deviceConfig;
static EyeProjectConfig s_config;
static EyeAnimator *s_animator = nullptr;
static DisplayHAL *s_display = nullptr;
static WiiChuckInput *s_wiiChuck = nullptr;
static GestureFaceInput *s_gestureFace = nullptr;
static EyeSyncManager *s_syncManager = nullptr;
static LightSensor *s_lightSensor = nullptr;
static LuxSensor *s_luxSensor = nullptr;

#if defined(DEBUG_OVERLAY_ENABLED)
static DebugOverlay s_debugOverlay;
#endif

std::shared_ptr<Arduino_IIC_DriveBus> IIC_Bus = std::make_shared<Arduino_HWIIC>(IIC_SDA, IIC_SCL, &Wire);

std::unique_ptr<Arduino_IIC> SY6970(new Arduino_SY6970(IIC_Bus, SY6970_DEVICE_ADDRESS,
                                                       DRIVEBUS_DEFAULT_VALUE, DRIVEBUS_DEFAULT_VALUE));

std::unique_ptr<Arduino_IIC> PCF85063(new Arduino_PCF85063(IIC_Bus, PCF85063_DEVICE_ADDRESS,
                                                           DRIVEBUS_DEFAULT_VALUE, DRIVEBUS_DEFAULT_VALUE));

void renderLoopTask(void *param);
void user_setup();
void user_loop();

/**
 * @brief Scan for I2C devices connected to a given I2C bus.
 *
 * @param wire Pointer to the TwoWire instance (e.g., &Wire or &Wire1).
 * @param name String identifier for the bus (e.g., "Wire", "Wire1").
 * @return void
 */
void debug_I2Cscan(TwoWire *wire, const char *name)
{
  Serial.printf("Scanning %s bus...\n", name);

  uint8_t nDevices = 0;
  for (uint8_t address = 8; address < 127; address++)
  {
    wire->beginTransmission(address);
    uint8_t error = wire->endTransmission();

    if (error == 0)
    {
      Serial.print("  I2C device found at address 0x");
      if (address < 16)
        Serial.print("0");
      Serial.print(address, HEX);
      Serial.println("!");
      nDevices++;
    }
    else if (error == 4)
    {
      Serial.print("  Unknown error at address 0x");
      if (address < 16)
        Serial.print("0");
      Serial.print(address, HEX);
      Serial.println("!");
    }
  }
  if (nDevices == 0)
    Serial.println("No I2C devices found.");
  else
    Serial.printf("Done. Found %u device(s).\n", nDevices);
}

/**
 * @brief Initialize the display based on the detected board.
 *
 * Instantiates either AMOLEDDisplay or TRGBDisplay and stores the
 * pointer in s_display. Configures dimensions in s_config.
 */
void setupDisplay()
{
#if ARDUINO_LILYGO_T_DISPLAY_S3_AMOLED
  static AMOLEDDisplay display;
  if (!display.begin())
  {
    Serial.println("T-Display S3 AMOLED init failed!");
    return;
  }
  s_display = &display;
  s_config.displayWidth = display.getWidth();
  s_config.displayHeight = display.getHeight();
#elif ARDUINO_LILYGO_T_RGB
  static TRGBDisplay display;
  if (!display.begin())
  {
    Serial.println("T-RGB init failed!");
    return;
  }
  s_display = &display;
  s_config.displayWidth = display.getWidth();
  s_config.displayHeight = display.getHeight();
#else
  Serial.println("No display configured!");
  return;
#endif

  Serial.printf("Display (%dx%d) configured successfully.\n", s_config.displayWidth, s_config.displayHeight);
}

/**
 * @brief Initialize and configure the PCF85063 RTC.
 *
 * Enables ADC measurement, configures charging thresholds, voltage
 * limits, and current limits for safe Li-Po operation.
 */
void setupPCF85063()
{
  if (PCF85063->begin())
  {
    Serial.println("PCF85063 initialized successfully.");
  }
  else
  {
    Serial.println("ERROR: PCF85063 failed to initialize!");
    return;
  }

  // Enable RTC.
  PCF85063->IIC_Write_Device_State(PCF85063->Arduino_IIC_RTC::Device::RTC_CLOCK_RTC,
                                   PCF85063->Arduino_IIC_RTC::Device_State::RTC_DEVICE_ON);
  // Disable RTC.
  PCF85063->IIC_Write_Device_State(PCF85063->Arduino_IIC_RTC::Device::RTC_CLOCK_RTC,
                                   PCF85063->Arduino_IIC_RTC::Device_State::RTC_DEVICE_OFF);

#if defined(PCF85063_DIAGNOSTIC_ENABLED)
  Serial.printf("\n--------------------PCF85063--------------------\n");
  Serial.printf("IIC_Bus.use_count(): %" PRId32 "\n", (int32_t)IIC_Bus.use_count());
  Serial.printf("ID: 0x%" PRIx32 "\n", (int32_t)PCF85063->IIC_Device_ID());

  Serial.printf("\nPCF85063  Weekday: %s\n",
                PCF85063->IIC_Read_Device_State(PCF85063->Arduino_IIC_RTC::Status_Information::RTC_WEEKDAYS_DATA).c_str());
  Serial.printf("PCF85063  Year: %" PRId32 "\n",
                (int32_t)PCF85063->IIC_Read_Device_Value(PCF85063->Arduino_IIC_RTC::Value_Information::RTC_YEARS_DATA));
  Serial.printf("PCF85063 Date: %" PRId32 ".%" PRId32 "\n",
                (int32_t)PCF85063->IIC_Read_Device_Value(PCF85063->Arduino_IIC_RTC::Value_Information::RTC_MONTHS_DATA),
                (int32_t)PCF85063->IIC_Read_Device_Value(PCF85063->Arduino_IIC_RTC::Value_Information::RTC_DAYS_DATA));
  Serial.printf("PCF85063 Time: %" PRId32 ":%" PRId32 ":%" PRId32 "\n",
                (int32_t)PCF85063->IIC_Read_Device_Value(PCF85063->Arduino_IIC_RTC::Value_Information::RTC_HOURS_DATA),
                (int32_t)PCF85063->IIC_Read_Device_Value(PCF85063->Arduino_IIC_RTC::Value_Information::RTC_MINUTES_DATA),
                (int32_t)PCF85063->IIC_Read_Device_Value(PCF85063->Arduino_IIC_RTC::Value_Information::RTC_SECONDS_DATA));
  Serial.printf("--------------------PCF85063--------------------\n\n");
#endif
}

/**
 * @brief Initialize and configure the SY6970 battery fuel gauge.
 *
 * Enables ADC measurement, configures charging thresholds, voltage
 * limits, and current limits for safe Li-Po operation.
 */
void setupSY6970()
{
  if (SY6970->begin())
  {
    Serial.println("SY6970 initialized successfully.");
  }
  else
  {
    Serial.println("ERROR: SY6970 failed to initialize!");
    return;
  }

  SY6970->IIC_Write_Device_State(SY6970->Arduino_IIC_Power::Device::POWER_BATFET_MODE, SY6970->Arduino_IIC_Power::Device_State::POWER_DEVICE_OFF);
  /*
  // Enable ADC measurement function.
  SY6970->IIC_Write_Device_State(SY6970->Arduino_IIC_Power::Device::POWER_DEVICE_ADC_MEASURE, SY6970->Arduino_IIC_Power::Device_State::POWER_DEVICE_ON);
  // Disable watchdog timer feeding function.
  SY6970->IIC_Write_Device_Value(SY6970->Arduino_IIC_Power::Device_Value::POWER_DEVICE_WATCHDOG_TIMER, 0);
  // Set thermal regulation threshold to 60 degrees.
  SY6970->IIC_Write_Device_Value(SY6970->Arduino_IIC_Power::Device_Value::POWER_DEVICE_THERMAL_REGULATION_THRESHOLD, 60);
  // Set charging target voltage to 4224mV.
  SY6970->IIC_Write_Device_Value(SY6970->Arduino_IIC_Power::Device_Value::POWER_DEVICE_CHARGING_TARGET_VOLTAGE_LIMIT, 4224);
  // Set minimum system voltage limit to 3600mV.
  SY6970->IIC_Write_Device_Value(SY6970->Arduino_IIC_Power::Device_Value::POWER_DEVICE_MINIMUM_SYSTEM_VOLTAGE_LIMIT, 3600);
  // Set OTG voltage to 5062mV.
  SY6970->IIC_Write_Device_Value(SY6970->Arduino_IIC_Power::Device_Value::POWER_DEVICE_OTG_VOLTAGE_LIMIT, 5062);
  // Set input current limit to 2100mA.
  SY6970->IIC_Write_Device_Value(SY6970->Arduino_IIC_Power::Device_Value::POWER_DEVICE_INPUT_CURRENT_LIMIT, 2100);
  // Set fast charging current limit to 2112mA.
  SY6970->IIC_Write_Device_Value(SY6970->Arduino_IIC_Power::Device_Value::POWER_DEVICE_FAST_CHARGING_CURRENT_LIMIT, 2112);
  // Set pre-charge current limit to 192mA.
  SY6970->IIC_Write_Device_Value(SY6970->Arduino_IIC_Power::Device_Value::POWER_DEVICE_PRECHARGE_CHARGING_CURRENT_LIMIT, 192);
  // Set termination charging current limit to 320mA.
  SY6970->IIC_Write_Device_Value(SY6970->Arduino_IIC_Power::Device_Value::POWER_DEVICE_TERMINATION_CHARGING_CURRENT_LIMIT, 320);
  // Set OTG current limit to 500mA.
  SY6970->IIC_Write_Device_Value(SY6970->Arduino_IIC_Power::Device_Value::POWER_DEVICE_OTG_CHARGING_LIMIT, 500);
  */

#if defined(SY6970_DIAGNOSTIC_ENABLED)
  Serial.printf("\n--------------------SY6970--------------------\n");
  Serial.printf("IIC_Bus.use_count(): %" PRId32 "\n", (int32_t)IIC_Bus.use_count());
  Serial.printf("IIC device ID: 0x%" PRIx32 "\n", (int32_t)SY6970->IIC_Device_ID());

  Serial.printf("\nBUS Status: %s\n",
                (SY6970->IIC_Read_Device_State(SY6970->Arduino_IIC_Power::Status_Information::POWER_BUS_STATUS)).c_str());
  Serial.printf("BUS Connection Status: %s\n",
                (SY6970->IIC_Read_Device_State(SY6970->Arduino_IIC_Power::Status_Information::POWER_BUS_CONNECTION_STATUS)).c_str());
  Serial.printf("Battery FET Status: %s\n",
                (SY6970->IIC_Read_Device_State(SY6970->Arduino_IIC_Power::Status_Information::POWER_BATFET_STATUS)).c_str());
  Serial.printf("Charging Status: %s\n",
                (SY6970->IIC_Read_Device_State(SY6970->Arduino_IIC_Power::Status_Information::POWER_CHARGING_STATUS)).c_str());
  Serial.printf("Input Source Status: %s\n",
                (SY6970->IIC_Read_Device_State(SY6970->Arduino_IIC_Power::Status_Information::POWER_INPUT_SOURCE_STATUS)).c_str());
  Serial.printf("Input USB Status: %s\n",
                (SY6970->IIC_Read_Device_State(SY6970->Arduino_IIC_Power::Status_Information::POWER_INPUT_USB_STATUS)).c_str());
  Serial.printf("System Voltage Status: %s\n",
                (SY6970->IIC_Read_Device_State(SY6970->Arduino_IIC_Power::Status_Information::POWER_SYSTEM_VOLTAGE_STATUS)).c_str());
  Serial.printf("Thermal Regulation Status: %s\n",
                (SY6970->IIC_Read_Device_State(SY6970->Arduino_IIC_Power::Status_Information::POWER_THERMAL_REGULATION_STATUS)).c_str());
  Serial.printf("\nWatchdog Fault Status: %s\n",
                (SY6970->IIC_Read_Device_State(SY6970->Arduino_IIC_Power::Status_Information::POWER_WATCHDOG_FAULT_STATUS)).c_str());
  Serial.printf("OTG Fault Status: %s\n",
                (SY6970->IIC_Read_Device_State(SY6970->Arduino_IIC_Power::Status_Information::POWER_OTG_FAULT_STATUS)).c_str());
  Serial.printf("Charging Fault Status: %s\n",
                (SY6970->IIC_Read_Device_State(SY6970->Arduino_IIC_Power::Status_Information::POWER_CHARGING_FAULT_STATUS)).c_str());
  Serial.printf("Battery Fault Status: %s\n",
                (SY6970->IIC_Read_Device_State(SY6970->Arduino_IIC_Power::Status_Information::POWER_BATTERY_FAULT_STATUS)).c_str());
  Serial.printf("NTC Fault Status: %s\n",
                (SY6970->IIC_Read_Device_State(SY6970->Arduino_IIC_Power::Status_Information::POWER_NTC_FAULT_STATUS)).c_str());

  Serial.printf("\nInput Voltage: %" PRId32 " mV\n",
                (int32_t)SY6970->IIC_Read_Device_Value(SY6970->Arduino_IIC_Power::Value_Information::POWER_INPUT_VOLTAGE));
  Serial.printf("Battery Voltage: %" PRId32 " mV\n",
                (int32_t)SY6970->IIC_Read_Device_Value(SY6970->Arduino_IIC_Power::Value_Information::POWER_BATTERY_VOLTAGE));
  Serial.printf("System Voltage: %" PRId32 " mV\n",
                (int32_t)SY6970->IIC_Read_Device_Value(SY6970->Arduino_IIC_Power::Value_Information::POWER_SYSTEM_VOLTAGE));
  Serial.printf("NTC Voltage Percentage: %.03f %%\n",
                (float)SY6970->IIC_Read_Device_Value(SY6970->Arduino_IIC_Power::Value_Information::POWER_NTC_VOLTAGE_PERCENTAGE) / 1000.0);
  Serial.printf("Charging Current: %" PRId32 " mA\n",
                (int32_t)SY6970->IIC_Read_Device_Value(SY6970->Arduino_IIC_Power::Value_Information::POWER_CHARGING_CURRENT));
  Serial.printf("Thermal Regulation Threshold: %" PRId32 " °C\n",
                (int32_t)SY6970->IIC_Read_Device_Value(SY6970->Arduino_IIC_Power::Value_Information::POWER_THERMAL_REGULATION_THRESHOLD));

  Serial.printf("\nCharging Voltage Limit: %" PRId32 " mV\n",
                (int32_t)SY6970->IIC_Read_Device_Value(SY6970->Arduino_IIC_Power::Value_Information::POWER_CHARGING_TARGET_VOLTAGE_LIMIT));
  Serial.printf("Minimum System Voltage Limit: %" PRId32 " mV\n",
                (int32_t)SY6970->IIC_Read_Device_Value(SY6970->Arduino_IIC_Power::Value_Information::POWER_MINIMUM_SYSTEM_VOLTAGE_LIMIT));
  Serial.printf("OTG Voltage Limit: %" PRId32 " mV\n",
                (int32_t)SY6970->IIC_Read_Device_Value(SY6970->Arduino_IIC_Power::Value_Information::POWER_OTG_VOLTAGE_LIMIT));
  Serial.printf("Input Current Limit: %" PRId32 " mA\n",
                (int32_t)SY6970->IIC_Read_Device_Value(SY6970->Arduino_IIC_Power::Value_Information::POWER_INPUT_CURRENT_LIMIT));
  Serial.printf("Fast Charge Current Limit: %" PRId32 " mA\n",
                (int32_t)SY6970->IIC_Read_Device_Value(SY6970->Arduino_IIC_Power::Value_Information::POWER_FAST_CHARGING_CURRENT_LIMIT));
  Serial.printf("Precharge Charge Current Limit: %" PRId32 " mA\n",
                (int32_t)SY6970->IIC_Read_Device_Value(SY6970->Arduino_IIC_Power::Value_Information::POWER_PRECHARGE_CHARGING_CURRENT_LIMIT));
  Serial.printf("Termination Charge Current Limit: %" PRId32 " mA\n",
                (int32_t)SY6970->IIC_Read_Device_Value(SY6970->Arduino_IIC_Power::Value_Information::POWER_TERMINATION_CHARGING_CURRENT_LIMIT));
  Serial.printf("OTG Current Limit: %" PRId32 " mA\n",
                (int32_t)SY6970->IIC_Read_Device_Value(SY6970->Arduino_IIC_Power::Value_Information::POWER_OTG_CURRENT_LIMIT));
  Serial.printf("--------------------SY6970--------------------\n\n");
#endif

  Serial.println("SY6970 configuration complete.");
}

/**
 * @brief Initialize WiiChuck, LightSensor, and DFRobot Gesture & Face Detection sensor input devices.
 *
 * Attempts to initialize a Wii Nunchuck and DFRobot Gesture
 * & Face Detection sensor on the I2C bus and a photoresistor
 * on LIGHT_PIN. Both are optional (sensor works without a
 * controller, and vice versa).
 */
void setupInput()
{
#if defined(QWIIC_SDA) && defined(QWIIC_SCL)
  static WiiChuckInput chuck(0x52, Wire1);
  static GestureFaceInput gfd(0x72, 640, 480, &Wire1);
  static LuxSensor lux(Wire1);
#else
  static WiiChuckInput chuck;
  static GestureFaceInput gfd;
  static LuxSensor lux(Wire);
#endif

  static LightSensor lightSensor(LIGHT_PIN);
  if (lightSensor.begin())
  {
    s_lightSensor = &lightSensor;
  }

  if (lux.begin())
  {
    s_luxSensor = &lux;
  }

  if (chuck.begin())
  {
    s_wiiChuck = &chuck;
  }

  if (gfd.begin())
  {
    s_gestureFace = &gfd;
  }
}

/**
 * @brief Configure the EyeAnimator with the detected light sensor.
 *
 * Reads the sensor's calibrated min/max and curve values and passes
 * them to EyeAnimator. When no sensor is connected, passes -1 to
 * enable autonomous iris animation instead.
 */
void setupLightSensor()
{
  if (s_luxSensor && s_luxSensor->isConnected())
  {
    s_animator->setLuxSensor(s_luxSensor);
    Serial.println("Lux sensor (MAX44009) configured.");
  }
  else if (s_lightSensor && s_lightSensor->isConnected())
  {
    s_animator->setLightSensor(
        s_lightSensor->getPin(),
        s_lightSensor->getMinValue(),
        s_lightSensor->getMaxValue(),
        s_lightSensor->getCurve());
    Serial.printf("Light sensor configured (Pin %u).\n", LIGHT_PIN);
  }
  else
  {
    s_animator->setLightSensor(-1, 0, 1023, 1.0f);
    Serial.println("No light sensor connected - using autonomous iris animation.");
  }
}

/**
 * @brief Initialize ESP-NOW networking.
 *
 * Sets WiFi to STA mode, initializes the EyeSyncManager, and registers
 * callbacks for peer events and incoming state data. Sends the local
 * MAC address to the serial console for pairing.
 */
void setupNetwork()
{
  WiFi.mode(WIFI_STA);
  WiFi.disconnect();

  static EyeSyncManager sync;

  // Apply security config before begin() so the PMK is set during esp_now_init.
  if (s_deviceConfig.networkToken != 0)
    sync.setNetworkToken(s_deviceConfig.networkToken);
  if (s_deviceConfig.loaded)
  {
    // Only set PMK when a key was explicitly provided (all-zero PMK = unset).
    bool hasPmk = false;
    for (int i = 0; i < 16 && !hasPmk; i++)
      hasPmk = s_deviceConfig.networkPmk[i] != 0;
    if (hasPmk)
      sync.setNetworkPmk(s_deviceConfig.networkPmk);
  }
  for (int i = 0; i < s_deviceConfig.allowedMacCount; i++)
    sync.addAllowedMac(s_deviceConfig.allowedMacs[i]);

  if (sync.begin(s_deviceConfig.networkChannel))
  {
    s_syncManager = &sync;

    sync.onDataReceived([](const EyeSyncMessage &msg, const uint8_t *mac)
                        { sync.setControllerMac(mac); });

    uint8_t mac[6];
    esp_wifi_get_mac(WIFI_IF_STA, mac);
    Serial.printf("ESP-NOW initialized (MAC: %02X:%02X:%02X:%02X:%02X:%02X).\n",
                  mac[0], mac[1], mac[2], mac[3], mac[4], mac[5]);
  }
  else
  {
    Serial.println("ERROR: ESP-NOW init failed!");
  }
}

/**
 * @brief Firmware initialization: peripherals, display, inputs, and animation.
 *
 * Initializes Serial, SY6970, display, debug overlay, WiiChuck, light sensor,
 * gesture/face sensor, network, and the EyeAnimator. Creates the renderLoopTask
 * on Core 1 at priority 1. This function does not return until the render task
 * takes over.
 */
void setup()
{
  Serial.begin(115200);
  delay(1000);

  Serial.println();
  Serial.println("===========================================");
  Serial.println("Uncanny Eyes for ESP32");
  Serial.print("Board: ");
#if ARDUINO_LILYGO_T_DISPLAY_S3_AMOLED
  Serial.println("T-Display S3 AMOLED");
#elif ARDUINO_LILYGO_T_RGB
  Serial.println("T-RGB");
#else
  Serial.println("Unknown");
#endif
  Serial.println("===========================================");

  SDConfig::load(s_deviceConfig, SD_CS, SD_SCLK, SD_MISO, SD_MOSI);

  // Use 100 kHz as a safe middle ground that works for all devices
  // on the shared I2C bus.
  if (Wire.begin(IIC_SDA, IIC_SCL, 100000))
  {
    Serial.println("Wire (I2C) initialized successfully.");
    debug_I2Cscan(&Wire, "Wire");
  }
  else
  {
    Serial.println("ERROR: Wire (I2C) failed to initialize!");
  }

#if defined(QWIIC_SDA) && defined(QWIIC_SCL)
  if (Wire1.begin(QWIIC_SDA, QWIIC_SCL, 100000))
  {
    Serial.println("Wire1 (QWIIC) initialized successfully.");
    debug_I2Cscan(&Wire1, "Wire1");
  }
  else
  {
    Serial.println("ERROR: Wire1 (QWIIC) failed to initialize!");
  }
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
void loop()
{
  static uint32_t lastStatus = 0;
  uint32_t now = millis();

  if (now - lastStatus > 5000)
  {
    lastStatus = now;

    Serial.printf("[%" PRIu32 "] Running...", now / 1000);
    if (s_wiiChuck)
      Serial.print(" WiiChuck");
    if (s_gestureFace)
      Serial.printf(" GestureFace(%u)", s_gestureFace->getFaceCount());
    if (s_luxSensor && s_luxSensor->isConnected())
      Serial.print(" MAX44009");
    if (s_lightSensor && s_lightSensor->isConnected())
      Serial.print(" LDR");
    if (s_syncManager)
    {
      s_syncManager->pruneDropped();
      Serial.printf(" ESP-NOW(%d peers)", s_syncManager->getPeerCount());
    }
    Serial.println();
  }

  delay(10);

  while (Serial.available())
  {
    char c = Serial.read();
    if (c == 'E')
    {
      int eyeIndex = Serial.parseInt();
      if (eyeIndex >= 0 && eyeIndex < s_eyeCount)
      {
        switchEye(eyeIndex);
      }
      else
      {
        Serial.printf("Invalid eye index. Available: 0-%d\n", s_eyeCount - 1);
      }
    }
    else if (c == 'U')
    {
      int flag = Serial.parseInt();
      if (s_display)
      {
        s_display->setRotation(flag ? 2 : 0);
        Serial.printf("Display %s.\n", flag ? "upside-down" : "normal");
      }
      else
      {
        Serial.println("Display not available.");
      }
    }
  }
}

void eyesBlink()
{
  if (s_animator)
    s_animator->eyesBlink();
}
void eyesBoop()
{
  if (s_animator)
    s_animator->eyesBoop();
}
void eyesClose()
{
  if (s_animator)
    s_animator->eyesClose();
}
void eyesWide()
{
  if (s_animator)
    s_animator->eyesWide();
}
void eyesNormal()
{
  if (s_animator)
    s_animator->eyesNormal();
}

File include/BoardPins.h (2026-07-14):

/**
 * @file BoardPins.h
 * @brief Board-specific pin definitions and I2C bus configuration.
 *
 * Maps the shared peripheral signals to the correct GPIO numbers for each
 * supported board (T-Display S3 AMOLED vs T-RGB).
 */
#ifndef BOARD_PINS_H
#define BOARD_PINS_H

// Display Configuration
#if defined(ARDUINO_LILYGO_T_DISPLAY_S3_AMOLED)
#define BOARD_NAME "T-Display S3 AMOLED"
#define LCD_WIDTH 466
#define LCD_HEIGHT 466
#define LCD_SDIO0 11
#define LCD_SDIO1 13
#define LCD_SDIO2 14
#define LCD_SDIO3 15
#define LCD_SCLK 12
#define LCD_CS 10
#define LCD_RST 17
#define LCD_EN 16
#elif defined(ARDUINO_LILYGO_T_RGB)
#define BOARD_NAME "T-RGB"
#define LCD_WIDTH 466
#define LCD_HEIGHT 466
#define LCD_SDIO0 11
#define LCD_SDIO1 13
#define LCD_SDIO2 14
#define LCD_SDIO3 15
#define LCD_SCLK 12
#define LCD_CS 10
#define LCD_RST 17
#define LCD_EN 16
#else
#define BOARD_NAME "Unknown"
#define LCD_WIDTH 466
#define LCD_HEIGHT 466
#endif

//  Quad SPI Configuration
#define QSPI_FREQUENCY 80000000

// I2C Bus Configuration
#if defined(ARDUINO_LILYGO_T_DISPLAY_S3_AMOLED)
#define IIC_SDA 7
#define IIC_SCL 6
#define QWIIC_SDA 43
#define QWIIC_SCL 44
#elif defined(ARDUINO_LILYGO_T_RGB)
// SDA/SCL per LilyGo's official utilities.h (BOARD_I2C_SDA/BOARD_I2C_SCL) —
// previously swapped here, which left most I2C devices (SY6970, the XL9555
// GPIO expander driving the ST7701S panel's command lines) unable to
// communicate, while the display panel itself never received its init
// sequence and stayed permanently blank.
#define IIC_SDA 8
#define IIC_SCL 48
#define QWIIC_SDA 43
#define QWIIC_SCL 44
#else
#define IIC_SDA 21
#define IIC_SCL 22
#endif

// Battery ADC
#define BATTERY_VOLTAGE_ADC_DATA 4

// Light Sensor
#define LIGHT_PIN 5

// RTC
#define PCF85063_INT 9

// SD Card
#define SD_CS 38
#define SD_MOSI 39
#define SD_MISO 40
#define SD_SCLK 41

// Touch
#define TP_INT 9

#endif // BOARD_PINS_H

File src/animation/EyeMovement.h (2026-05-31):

/**
 * @file EyeMovement.h
 * @brief Saccadic eye movement generator with lognormal distribution and centering bias.
 *
 * Human eye movements naturally follow a lognormal distribution — most are small
 * microsaccades (~0.5-2°) with occasional larger saccades. This module generates
 * realistic autonomous eye movement using that distribution, applies a centering
 * bias to pull the eye back toward center after peripheral movements, and uses
 * sigmoid easing to approximate the characteristic velocity profile of real saccades.
 *
 * Tuning guide: Each parameter section includes a description of its effect and
 * recommended range. Increasing a parameter moves behavior in that direction.
 *
 * ============================================================================
 * SACCADE / EYE MOVEMENT PARAMETERS
 * ============================================================================
 *
 * Lognormal Distribution Parameters
 * --------------------------------
 * These control the amplitude (size) distribution of random eye movements.
 * Lognormal is used because real saccades follow this distribution — most
 * movements are small, with a long tail of larger movements.
 *
 * EYE_MOVE_LOGNORMAL_SIGMA: Spread/shape of the amplitude distribution.
 *   Higher = more variation, more large saccades. Range: 0.2-0.6. Default: 0.35.
 *
 * EYE_MOVE_LOGNORMAL_OFFSET: Shifts the distribution (negative = smaller avg).
 *   Range: -0.4 to 0.1. Default: -0.2.
 *
 * EYE_MOVE_AMPLITUDE_SCALE: Scales lognormal output relative to bounds radius.
 *   Range: 0.0-1.0. Default: 0.5.
 *
 * EYE_MOVE_MIN_AMPLITUDE: Minimum movement amplitude (prevents zero/stuck).
 *   Range: 0.005-0.02. Default: 0.01.
 *
 * EYE_MOVE_MAX_AMPLITUDE_SCALE: Max amplitude as fraction of bounds radius.
 *   Range: 0.0-1.0. Default: 0.8.
 *
 * EYE_MOVE_BOUNDS_RADIUS: Movement boundary radius (fraction of display half-width).
 *   Controls how far from center the pupil can travel. Range: 0.3-0.8. Default: 0.6.
 *
 * Centering Bias Parameters
 * ------------------------
 * These control how strongly the eye is pulled back toward center after a movement.
 * This mimics natural behavior where peripheral movements trigger corrective glances.
 *
 * EYE_MOVE_CENTER_BIAS_FACTOR: Strength of centering pull (0.0-1.0). Default: 0.6.
 * EYE_MOVE_CENTER_BIAS_MAX: Cap on centering effect (0.0-0.5). Default: 0.5.
 *
 * Movement Duration Parameters
 * --------------------------
 * Real saccades range from ~100ms (small) to ~300ms (large).
 *
 * EYE_MOVE_BASE_DURATION_MIN/MAX: Base duration for small movements (ms). Default: 200-350.
 * EYE_MOVE_DURATION_DISTANCE_SCALE: Extra duration scaled by distance (ms). Default: 150.
 * EYE_MOVE_DURATION_MIN/MAX: Hard limits on duration (ms). Default: 150-500.
 *
 * Fixation / Idle Timing Parameters
 * ---------------------------------
 * EYE_MOVE_FIXATION_PAUSE_MIN/MAX: Pause between random saccades (ms). Default: 12000-50000.
 *   Long pauses with wide random spread create the natural "dwell then dart" rhythm.
 *   Increase MIN for a lazier gaze; decrease MAX to keep the eye more active.
 *
 * EYE_MOVE_SACCADE_DELAY: Delay before resuming autonomous saccades after an external
 *   target (joystick or face) is lost (ms). Default: 4000.
 *
 * Saccade Easing Parameters
 * -------------------------
 * Real saccades have rapid acceleration/deceleration; sigmoid easing approximates this.
 *
 * EYE_MOVE_EASING_STEEPNESS: Sharpness of the easing transition. Range: 1.0-5.0. Default: 3.0.
 *
 * Joystick Smooth-Follow Parameters
 * ----------------------------------
 * Applied per frame at ~120 FPS via adaptive exponential smoothing.
 * Alpha = BASE + distance * DIST, clamped to [0, 1].
 *   JOYSTICK_BASE_ALPHA: minimum blend per frame (small-movement smoothness).
 *   JOYSTICK_DIST_ALPHA: extra blend per unit of distance (large-move responsiveness).
 * At dist=0.0: alpha=0.12 → ~140 ms settling; at dist=0.6: alpha=0.30 → ~80 ms.
 *
 * ============================================================================
 * EYELID / BLINK PARAMETERS
 * ============================================================================
 * Human blinks: quick closing, brief pause at closure, slower opening.
 *
 * BLINK_DURATION_CLOSE_MIN/MAX: Closing phase duration (ms). Default: 60-100.
 * BLINK_DURATION_OPEN_MIN/MAX: Opening phase duration (ms). Default: 120-200.
 * BLINK_PAUSE_AT_CLOSURE: Pause at full closure (ms). Default: 20.
 *
 * BLINK_INTERVAL_MIN/MAX: Random interval between automatic blinks (ms). Default: 2000-8000.
 * BLINK_PROBABILITY_BURST: Chance of double-blink (0.0-1.0). Default: 0.15.
 * BLINK_CHANCE_AFTER_SACCADE: Chance of blink after eye movement. Default: 0.08.
 *
 * EYELID_UPPER_TRACK_STRENGTH: How much upper eyelid tracks pupil (0.0-1.0). Default: 0.3.
 * EYELID_LOWER_TRACK_STRENGTH: How much lower eyelid tracks pupil. Default: 0.15.
 * EYELID_SQUINT_FACTOR: Eyelid closure during squint (0.0-1.0). Default: 0.7.
 * EYELID_NORMAL_CLOSURE_DEFAULT: Resting eyelid coverage (0.0=open, 1.0=closed). Default: 0.15.
 * EYELID_WIDE_CLOSURE_DEFAULT: Wide/surprised eyelid coverage. Default: 0.0.
 * EYELID_SMOOTHING: Smoothing factor for eyelid position changes. Default: 0.1.
 * BLINK_USE_SMOOTHSTEP: Enable smoothstep easing (0/1). Default: 1.
 *
 * Forced Expression Animation Durations
 * --------------------------------------
 * When the Z or C button is pressed or released the eyelid animates smoothly
 * to the target position using smoothstep easing instead of snapping instantly.
 *
 * EYELID_CLOSE_DURATION: ms to animate to fully closed on Z-button hold.
 *   Faster feels reflexive; slower feels deliberate. Range: 80-300. Default: 150.
 *
 * EYELID_WIDE_DURATION: ms to animate to wide-open on C-button hold.
 *   Should feel like mild surprise — quick but not snappy. Range: 80-250. Default: 130.
 *
 * EYELID_NORMAL_DURATION: ms to animate back to the resting gap on button release.
 *   A slower return feels more relaxed and natural. Range: 150-500. Default: 230.
 *
 * PUPIL_WIDE_DURATION: ms to constrict pupil on C-button hold. Default: 100.
 * PUPIL_RELEASE_DURATION: ms to return pupil to normal on C-button release. Default: 150.
 *
 * ============================================================================
 * PUPIL / IRIS AUTONOMOUS ANIMATION (HIPPUS) PARAMETERS
 * ============================================================================
 * Human pupils exhibit slow spontaneous oscillation at rest (hippus). This models
 * that behavior: the pupil drifts toward a new target over a slow transition, holds
 * briefly, then drifts again. All timing values are in milliseconds.
 *
 * IRIS_AMPLITUDE_SCALE: Normal-distribution sigma for the drift amplitude (normalized
 *   0-1 fraction of the pupil range). Smaller = subtler oscillation. Default: 0.07.
 *
 * IRIS_AMPLITUDE_MAX: Hard clip on drift amplitude (normalized). Default: 0.15.
 *
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

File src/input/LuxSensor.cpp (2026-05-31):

/**
 * @file LuxSensor.cpp
 * @brief Implementation of Adafruit MAX44009 ambient light sensor for pupil size control.
 *
 * Uses the Adafruit_MAX44009 library via I2C to read ambient lux values.
 * Auto-detects sensor presence using the library's begin() method.
 * Performs auto-ranging on begin() to establish calibrated min/max bounds.
 * Applies time-based exponential smoothing to pupil factor changes for
 * realistic, gradual iris transitions.
 */
#include <Arduino.h>
#include "LuxSensor.h"

LuxSensor::LuxSensor(TwoWire &wire) : m_sensor(), m_wirePtr(&wire) {}

bool LuxSensor::begin()
{
  // Adafruit_I2CDevice::begin() calls Wire.begin() internally which resets ESP32
  // I2C state, causing the first endTransmission() to return 0 spuriously.
  // Pre-check while the bus is already in a clean initialized state.
  m_wirePtr->beginTransmission(MAX44009_DEFAULT_ADDRESS);
  if (m_wirePtr->endTransmission() != 0)
  {
    m_connected = false;
    Serial.println("[LuxSensor] MAX44009 not found at 0x4A");
    return false;
  }

  if (!m_sensor.begin(MAX44009_DEFAULT_ADDRESS, m_wirePtr))
  {
    m_connected = false;
    Serial.println("[LuxSensor] MAX44009 not found at 0x4A");
    return false;
  }

  m_connected = true;
  m_pupilFactor = 0.5f;
  m_pupilFactorPrev = 0.5f;
  m_lastUpdate = millis();
  Serial.println("[LuxSensor] MAX44009 initialized at 0x4A");

  float luxSum = 0.0f;
  uint8_t validSamples = 0;
  for (int i = 0; i < 16; i++)
  {
    float lux = m_sensor.readLux();
    if (lux >= 0.0f)
    {
      luxSum += lux;
      validSamples++;
    }
    delay(20);
  }

  if (validSamples == 0)
  {
    m_connected = false;
    Serial.println("[LuxSensor] MAX44009: no valid readings during calibration");
    return false;
  }

  float avgLux = luxSum / validSamples;
  m_minLux = avgLux * 0.5f;
  m_maxLux = avgLux * 2.0f;

  if (m_minLux < 0.01f)
    m_minLux = 0.01f;
  if (m_maxLux < m_minLux + 10.0f)
    m_maxLux = m_minLux + 1000.0f;
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

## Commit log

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2026-05-22 Debugging and feature correction.
    * Removed ispin parameter.
    * Fixed eye movement.
    [EyeAnimator.cpp, EyeMovement.h, EyeRenderer.cpp]
2026-05-22 Debugging and feature correction.
    * Fixed pupil movement.
    * Fixed eyelid and custom eyelid image support.
    * Added light sensor support.
    [BlinkFSM.h, EyeAnimator.cpp, EyeAnimator.h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]
2026-05-22 Cleanup and bugfixes.
    * Consolidated pin definitions.
    * Updated README.md file.
    * Fixed pupil animation.
    * Added additional Doxygen comments.
    [AMOLEDDisplay.cpp, BoardPins.h, EyeAnimator.cpp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]
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2026-05-24 Debugging and feature correction.
    [AMOLEDDisplay.cpp, BoardPins.h, GestureFaceInput.cpp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]
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2026-05-24 Fix frame buffer clear corrupting non-uniform 16-bit background colors
    memset() fills byte-by-byte, so a bgColor like 0x1234 would write 0x3434
    to every pixel instead of 0x1234. Replace with std::fill() which operates
    on the correct element width.
    [EyeRenderer.cpp]
2026-05-24 Fix cross-core race when switching eye definitions via serial command
    setEyeIndex() was called from Core 0 (loop()) and directly reinitialised
    the renderer and swapped PSRAM buffer pointers while Core 1 (renderLoopTask)
    could be inside renderFrame() reading those same pointers.
    Replace the direct switch with a deferred mechanism: setEyeIndex() now
    stores the requested index in an atomic<int>, and update() (which runs on
    Core 1 before any rendering) atomically claims and applies it. This keeps
    all renderer mutations on Core 1, eliminating the data race.
    [EyeAnimator.cpp, EyeAnimator.h]
2026-05-24 Cache custom-lid detection in begin() instead of scanning every frame
    The per-frame hasCustomLids scan in renderFrame() used a fixed stride of
    47 pixels, which left the rightmost 43 columns of a 466-wide display
    unsampled. An eyelid with data only in that zone would silently fall
    back to the non-custom rendering path.
    Replace the scan with a flag computed once in begin() that walks every
    column. Since the eyelid tables never change between begin() calls,
    there is no reason to repeat the scan per frame. Also guard the PSRAM
    and scratch-buffer allocations in begin() so repeated calls (eye
    switches) do not allocate duplicate buffers and leak the originals.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
    [EyeRenderer.cpp]
2026-05-24 Remove dead null-guard and hardcoded width fallback in directTransfer
    gfx is already asserted non-null by the guard at the top of the function,
    making the inner if (gfx) branch unreachable. The initialiser fbWidth=480
    that preceded it was therefore the only code path that could ever run,
    silently hardcoding 480 even on a display whose width() differs.
    Replace both with a direct gfx->width() call.
    [TRGBDisplay.cpp]
2026-05-24 Make boop expression visually distinct from eyesWide
    eyesBoop() previously set a flag that was never acted upon, making boop
    and wide look identical (both did nothing or both showed the same eyelid
    state depending on input handling).
    Boop now produces a contrasting expression:
    - eyesWide: eyelids fully open (factor 0.0), pupils unchanged
    - eyesBoop: heavy squint (factor 0.6), pupils fully dilated (m_irisMin),
    auto-reverts to normal after BOOP_DURATION_MS (1500 ms)
    The squint overrides any normal() call that would have cancelled it, and
    the pupil override is applied after the light-sensor / autonomous-iris
    update so it wins regardless of which iris path is active. The boop is
    not re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
    [EyeAnimator.cpp, EyeAnimator.h]
2026-05-24 Fix boop being overridden by wide() while C button stays held
    wantsBoop() is edge-triggered — true for exactly one frame when C+Z
    are first pressed together. On every subsequent frame both wantsWide()
    and wantsClose() return true (C and Z are still held), so the old
    else-if chain would call eyesWide() on frame 2 onwards, fighting the
    boop squint and making it look like wide() was running simultaneously.
    Move the wantsWide/wantsClose/eyesNormal block inside an else-if(!m_booped)
    guard so that all hold-state expressions are suppressed for the full
    BOOP_DURATION_MS while a boop is active.
    [EyeAnimator.cpp]
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2026-05-24 Retry WiiChuck handshake to fix occasional cold-start failures
    The single-shot handshake would fail and return false if the Nunchuck
    was not yet ready to ACK at the moment begin() ran. This left the
    controller permanently disabled until the device was restarted.
    Three changes make initialisation robust:
    - 100 ms settling delay before the first attempt to cover cold-start
    and warm-reset timing races.
    - Both handshake writes (0xF0/0x55 and 0xFB/0x00) are now checked;
    previously only the second was, so a NACK on step 1 was silently
    ignored and step 2 would then also fail.
    - The full two-step sequence is retried up to 5 times with 50 ms
    between attempts, with per-attempt diagnostics pri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
    [WiiChuck.cpp]
2026-05-24 Replace joystick saccade hops with adaptive exponential smoothing
    The previous joystick path called moveTo() only when not already moving,
    producing a series of discrete 150 ms saccades: the eye would sit at a
    completed position, snap to where the joystick now was, then animate for
    another 150 ms — repeating every update cycle. setTarget() also shifted
    the endpoint of an in-flight saccade, causing erratic mid-move redirections.
    Replace with per-frame adaptive exponential smoothing:
    alpha = clamp(JOYSTICK_BASE_ALPHA + dist * JOYSTICK_DIST_ALPHA, 0, 1)
    smoothX += alpha * (target - smoothX) (same for Y)
    The blend factor scales with the distance between the smoothed position
    and the raw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
    [EyeAnimator.cpp, EyeAnimator.h, EyeMovement.h]
2026-05-24 Fix ESP-NOW: register broadcast peer and auto-discover peers
    Three bugs prevented any ESP-NOW communication:
    1. begin() never called esp_now_add_peer() — ESP-NOW requires all
    destinations to be registered before esp_now_send() will accept them.
    Now registers FF:FF:FF:FF:FF:FF as a broadcast peer at init so
    devices find each other without hardcoded MAC addresses.
    2. broadcast() iterated m_peerMACS[] (always empty) and called
    esp_now_send() on addresses not registered with the stack.
    Now sends to the broadcast MAC in a single call.
    3. onDataReceived() never registered the sender, so m_peerCount
    stayed at 0 forever, and broadcastState() would short-circuit
    on non-contr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
    [EyeSync.cpp, EyeSync.h]
2026-05-24 Fix ESP-NOW: controller always broadcasts, followers don't override joystick
    Three bugs prevented eyes from syncing despite packets being received:
    1. isController() returned m_input->hasExclusiveControl(), which is false
    when the joystick is centered. With 0 peers and isController()=false,
    broadcastState() short-circuited and the controller never sent state
    while the joystick was at rest. Changed to m_input != nullptr so the
    controller always broadcasts whenever a WiiChuck is attached.
    2. processNetworkInput() had no guard against running on the controller.
    When the follower broadcasts back (once it receives from the controller),
    the controller receives the follower's st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
    [EyeAnimator.cpp, EyeAnimator.h, EyeSync.cpp]
2026-05-24 Fix follower eye not tracking controller: use setCurrentPosition() in processNetworkInput
    setTarget() only stores coordinates; it does not start movement. When
    m_moving is false and m_randomMode is false, EyeMovement::update() returns
    immediately, so the follower's eye never moved regardless of what the
    controller sent.
    Replaced setTarget() with setCurrentPosition(), which directly writes the
    received position into the movement system each frame — the same approach
    the joystick smooth-follow uses. Also removed the eyeX != 0 guard, which
    would silently skip the entire block whenever the eye was centered, and
    cleaned up the nested time checks into a single staleness path that resumes
    autono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
    [EyeAnimator.cpp]
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2026-05-24 Add ESP-NOW peer drop detection with log message
    Tracks a last-seen timestamp per peer slot, refreshed by addPeer() on
    every received packet. pruneDropped() (called from the 5-second loop()
    heartbeat) scans the list and logs any peer silent beyond the 5-second
    threshold, then removes it with swap-with-last compaction so getPeerCount()
    accurately reflects active peers in the status line.
    If the dropped peer is the registered controller, hasController() is reset
    to false so processNetworkInput() short-circuits and the follower resumes
    autonomous movement immediately rather than waiting for the 100 ms staleness
    check each frame.
    [EyeSync.cpp, EyeSync.h, main.cpp]
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2026-05-24 Fix SDConfig build error: remove BoardPins.h from SDConfig.cpp
    BoardPins.h defines LCD_CS as a preprocessor macro (#define LCD_CS 10).
    When SDConfig.cpp included BoardPins.h before <Arduino.h>, the board
    variant header (pins_arduino.h) tried to declare:
    static const uint8_t LCD_CS = 6;
    The macro expanded LCD_CS to 10, producing:
    static const uint8_t 10 = 6; // syntax error
    Fix: remove #include "BoardPins.h" from SDConfig.cpp entirely. The SD pin
    constants (SD_CS/SCLK/MISO/MOSI) are now passed as parameters from
    main.cpp, which already has a safe include order. This also makes SDConfig
    board-agnostic — it knows nothing about pin assignments.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
    [SDConfig.cpp, main.cpp]
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2026-05-26 fix: four animation bugs + render loop optimization
    Issue 1 (joystick resume): After joystick release the 400ms center-return
    move completed into the 12-50s fixation pause instead of the 4s saccade
    delay. Added one-shot m_postMoveIdleMs to EyeMovement; EyeAnimator sets it
    to EYE_MOVE_SACCADE_DELAY before moveTo(0,0,400) so random saccades resume
    promptly.
    Issue 2 (edge flicker): Double-buffered PSRAM render buffer retained stale
    eye pixels from 2 frames ago outside the current dirty rect. Fix expands the
    render bounding box to cover m_prevDirtyMinX/Y/MaxX/Y so the existing
    bgColorBE fill loop naturally overwrites stale content. m_prevDirty
    initialized to empty at begin() to avoid spurious f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
    [EyeAnimator.cpp, EyeMovement.h, EyeRenderer.cpp]
2026-05-27 fix: correct prevDirty tracking, revert broken inner loop opt, revert SPI chunk size
    Edge flicker fix (take 2): the single m_prevDirtyMinX/Y/MaxX/Y scalar was shared
    across both double buffers. Buffer 0 is written at frames 1,3,5... and buffer 1 at
    frames 2,4,6... Each buffer's stale content is from 2 frames ago, not 1, so they
    need independent tracking. Changed to m_prevDirtyMinX[2] arrays indexed by bufIdx
    (0=frameBuf1, 1=frameBuf2). begin() initializes both slots to empty rects.
    Performance regression fix: the previous inner loop optimization hoisted qx/r before
    the iris/sclera branch. For non-textured pixels (no radius map), the fallback
    sqrtf((float)(dx*dx+dySq)) was computed unconditi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
    [EyeRenderer.cpp]
2026-05-27 Fix SPI panic when switching to eagle eye with custom textures
    Root cause: ESP32-S3 PSRAM is not DMA-capable (esp_ptr_dma_capable returns
    false for external RAM). The SPI driver allocates a per-transaction DRAM bounce
    buffer for every PSRAM transfer. After eagle eye loads iris/sclera texture caches
    into DRAM (~173 KB), only ~14 KB of contiguous DMA-capable memory remains --
    insufficient for the 16 KB bounce buffer needed per 8192-pixel chunk.
    Fix: copy each chunk from the PSRAM frame buffer into the GFX library's
    pre-allocated DRAM _buffer (MALLOC_CAP_DMA, allocated at boot when DRAM is
    plentiful) before handing it to the SPI transaction. The patch to
    arduino_esp32qspi_chunk_size.patch is u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
    [EyeRenderer.cpp]
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2026-05-27 Async render+transfer overlap via FreeRTOS task on Core 0.
    Transfer task (priority 5, Core 0) waits on m_xferReady semaphore, calls
    directTransfer, records duration into m_xferUs, then signals m_xferDone.
    renderFrame() takes m_xferDone at entry, renders, swaps buffers, then gives
    m_xferReady. Eagle render=53ms > xfer=19ms so transfer is always done before
    the next frame starts. Expected: eagle ~19 FPS (was ~13), default ~33 FPS.
    [EyeRenderer.cpp]
2026-05-27 Fix async overlap: move semaphore wait to after render, not before.
    Moving xSemaphoreTake(m_xferDone) from the top of renderFrame() to just
    before the buffer swap lets render and transfer run concurrently on their
    respective cores. Previous placement blocked at entry, eliminating the
    overlap entirely. Result: default eye 27-29 FPS (was 20 FPS); render and
    transfer times both increase slightly from PSRAM bus contention (~34ms/
    ~25ms vs 30ms/19ms sequential) but overlap saves the net serial wait.
    [EyeRenderer.cpp]
2026-05-27 Per-row zone precomputation + angle->texture row pointer table.
    Zone limits (xPupilLim, xIrisLim = max |dx| in each zone) computed per row
    from radius map + sqrtf, replacing per-pixel r-based zone comparisons with
    qx comparisons. Non-textured eyes no longer load radiusRow[qx] at all in
    the hot path. irisAnglePtrs[256]/scleraAnglePtrs[256] built in begin(),
    replacing the per-pixel multiply (fullAngle * texH) with a table-indexed
    load. Slit-pupil and no-radius-map cases fall back to original code path.
    [EyeRenderer.cpp]
2026-05-27 Invert joystick axes to match correct eye orientation.
    [EyeAnimator.cpp, EyeRenderer.cpp, WiiChuck.cpp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]
2026-05-30 Add MAX44009 light sensor support and tunable pupil smoothing.
    - Add LuxSensor driver for MAX44009 I2C ambient light sensor with time-based exponential smoothing.
    - Refactor iris.radiusFraction → maxFraction and add iris.minFraction for configurable minimum pupil size.
    - Introduce PUPIL_SMOOTH_ALPHA (default 0.05) as a single tunable parameter controlling pupil transition speed for both LDR and MAX44009 sensors.
    - Status line now reports active light sensors.
    - Fix inverted pupil direction when using light sensor.
    [EyeAnimator.cpp, EyeAnimator.h, EyeMovement.h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]
2026-05-30 Smooth pupil transitions for boop expression.
    - Smoothstep-eased pupil animation on boop entry (dilate) and exit (restore), matching the pattern used by eyesWide().
    - Added BOOP_PUPIL_DURATION 120 and animation state variables to track the pre-boop pupil value so it restores cleanly rather than snapping.
    [EyeAnimator.cpp, EyeAnimator.h, EyeMovement.h]
2026-05-30 Fixes to LDA sensor.
    - Added OVERSAMPLE_COUNT = 4 constant.
    - Changed update() to average 4 ADC samples per reading instead of single-point sampling.
    - Added m_irisCenterPrev and m_lightSmoothAlpha = 0.2f for EMA smoothing of the iris center.
    - Fixed constructor initializer order (reorder warning); updateLightSensor() now applies EMA smoothing.
    [EyeAnimator.cpp, EyeAnimator.h, EyeMovement.h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]
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2026-05-31 Fixes to gesture sensor.
    [EyeAnimator.cpp, EyeAnimator.h, EyeMovement.h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]
2026-06-01 perf: place renderFrame in IRAM to eliminate instruction-cache stalls
    [EyeRenderer.cpp]
2026-06-01 perf: zone-split inner render loop; packed 32-bit fill for pupil and solid spans
    Left/right halves each have a fixed angleSign eliminating the per-pixel dx<0
    conditional. Zone membership is determined by precomputed xPupilLim/xIrisLim
    boundaries, replacing the per-pixel qx comparisons. Pupil span and solid-color
    sclera/iris spans use fill16packed (two pixels per 32-bit store).
    [EyeRenderer.cpp]
2026-06-01 perf: precompute per-row circle and iris x-extent tables; eliminate 2x sqrtf per row
    xCircHalfW[qy] and xIrisLimTab[qy] (each 466 bytes DRAM) are built in begin()
    from the fixed eyeRadius/irisRadius. renderFrame() uses table lookups instead
    of sqrtf + correction loops for the two constant-geometry bounds. qy is now
    computed at the top of the row loop so both the circle-extent and texture-lookup
    sections can share it.
    [EyeRenderer.cpp]
2026-06-01 perf: increase QSPI clock 80MHz -> 90MHz; within CO5300 write cycle spec
    CO5300 minimum write cycle time is 12ns (~83MHz); 90MHz = 11.1ns is within
    that margin. Requires visual inspection on hardware — revert to 80000000 if
    display artifacts appear.
    [BoardPins.h]
2026-06-01 perf: replace per-pixel background fills with 32-bit packed fill16packed
    Left-gap, right-gap, and eyelid-row fills now use fill16packed, halving
    the number of PSRAM store operations for background spans.
    [EyeRenderer.cpp]
2026-06-01 revert: restore QSPI_FREQUENCY to 80MHz (CO5300 hardware maximum)
    90MHz exceeded the CO5300 panel's write cycle specification.
    [BoardPins.h]
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2026-06-21 fix: QSPI DMA buffer oversizing and negative-count fill16packed crash
    Two unrelated crashes, fixed together:
    1. A filename-keyed sentinel let patch_libdeps.py silently skip a newly
    added hunk after the patch file was edited, leaving
    Arduino_ESP32QSPI::_2nd_buffer allocated at full size (32KB) instead
    of 64 bytes, and max_transfer_sz at a stale *16 multiplier. Together
    this doubled permanently-reserved internal DMA-capable DRAM, starving
    the SPI driver and crashing during display writeBytes/POLL_END.
    Sentinels now hash patch content (not just filename) so edits can't
    be silently skipped, and apply_hunk() is idempotent so re-running an
    already-applied patch against a f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
    [EyeRenderer.cpp]
2026-06-21 fix: Core 0 watchdog starvation from zero-gap QSPI transfer loop
    EyeRenderer::xferTaskFunc (Core 0, priority 5) was handing off with the
    render task fast enough that it never left a real idle gap, eventually
    starving IDLE0 long enough to trip the Task Watchdog. This was previously
    misdiagnosed as a "Cache error/MMU fault" because the board's native-USB
    serial silently drops panic banners; pulling the flash coredump instead
    gave the real panic reason directly.
    Add a guaranteed vTaskDelay(1) after each transfer so the scheduler always
    gets a tick to run IDLE0, and correct the now-fictional "~120 FPS" framing
    in main.cpp (actual throughput is ~35-45 FPS, bound by the ~27ms QSPI
    transfer, not t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
    [EyeRenderer.cpp, main.cpp]
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2026-06-24 fix: pupil dilation read iris.minFraction instead of pupil.minFraction
    EyeAnimator set the pupil range from the iris config's minFraction field
    instead of the pupil's own minFraction. Removed the now-dead/duplicate
    IrisConfig::minFraction field entirely (eyes.h, geneye.py) rather than
    patching only the call sites, so it can't be silently reintroduced.
    Also retunes the eagle eye (smaller radius, larger iris, no sclera
    texture) and updates the README .eye config field table accordingly.
    [EyeAnimator.cpp]
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2026-06-24 feat: flip directTransfer output 180° on T-RGB when rotation=2
    [TRGBDisplay.cpp]
2026-06-24 docs: restore directTransfer doc comment; fix: U command serial feedback when display is null
    [TRGBDisplay.cpp, main.cpp]
2026-07-14 fix: move SD card SPI off the AMOLED's shared QSPI peripheral
    SDConfig::load() used Arduino's default SPI object (FSPI), which on
    ESP32-S3 maps to the same physical SPI2 peripheral as the AMOLED's
    QSPI bus (ESP32QSPI_SPI_HOST = SPI2_HOST). Two independent driver
    layers touching the same hardware (Arduino's raw register-poking HAL
    for the SD card vs. the ESP-IDF spi_master driver for the display) is
    a latent hazard, so give the SD card its own HSPI bus instead.
    [SDConfig.cpp]
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2026-07-14 fix: correct T-RGB board macro in setupDisplay()
    setupDisplay() checked #elif IS_TRGB, but IS_TRGB is never defined
    anywhere in the build — only ARDUINO_LILYGO_T_RGB is set via the
    trgb env's build_flags. The T-RGB branch was dead code, so TRGBDisplay
    never got instantiated and the board fell through to "No display
    configured!".
    [main.cpp]
2026-07-14 fix: bail out of setupPCF85063/setupSY6970 when init fails
    Both functions fell through to calling IIC_Write_Device_State/Value on
    a device that just reported begin() failure, instead of stopping at
    the error. Add the missing return in each failure branch.
    [main.cpp]
2026-07-14 fix: correct swapped T-RGB I2C SDA/SCL pins
    IIC_SDA/IIC_SCL were swapped (48/8 instead of 8/48) for
    ARDUINO_LILYGO_T_RGB, contradicting LilyGo's own utilities.h. This left
    the I2C bus effectively non-functional for most devices on it,
    including the XL9555 GPIO expander that bit-bangs the ST7701S panel's
    CS/SCK/MOSI command lines — so the panel never received its init/wake
    sequence and stayed permanently blank, while every software layer
    (DPI clock, framebuffer, backlight) reported success since nothing
    validated the expander was actually reachable. SY6970 and the touch
    controller were silently failing for the same reason.
    [BoardPins.h]
2026-07-14 fix: only byte-swap pixels for displays whose bus needs it
    EyeRenderer/EyelidRenderer unconditionally pre-swapped every pixel
    color to big-endian for directTransfer(), a requirement specific to
    AMOLED's raw QSPI byte stream (writeBytes). TRGBDisplay's
    directTransfer() instead memcpy's into the RGB panel's own
    native-endian framebuffer, so the same swap corrupted every color
    there (most visibly the iris, since black/white are swap-invariant
    and masked the bug elsewhere).
    Add DisplayHAL::needsByteSwappedPixels() (default false), overridden
    true only for AMOLEDDisplay, and gate all six swap call sites on it.
    [EyeRenderer.cpp, EyelidRenderer.h]
2026-07-14 fix: flush PSRAM cache in T-RGB directTransfer; add backlight PWM
    directTransfer() wrote pixels into the PSRAM framebuffer via plain
    memcpy, unlike every one of Arduino_GFX's own draw calls, which flush
    the CPU data cache back to PSRAM afterward (Cache_WriteBack_Addr).
    The DPI panel's DMA reads PSRAM directly, bypassing cache, so writes
    that skipped this call could sit stale or invisible to the panel.
    Also pin the DPI pixel clock to 8MHz (LilyGo's own
    RGB_MAX_PIXEL_CLOCK_HZ) instead of Arduino_GFX's auto-selected 12MHz,
    which it picks whenever CONFIG_SPIRAM_MODE_QUAD isn't defined — true
    here since this board uses octal PSRAM.
    setBrightness()/setBacklight() were stubbed on T-RGB; drive t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
    [TRGBDisplay.cpp]
2026-07-19 fix: correct AMOLED upside-down flip and QSPI bus race
    Arduino_CO5300::setRotation()'s own MADCTL bit values did not flip this
    panel (confirmed empirically); write MADCTL directly with the standard
    MIPI DCS MX|MY byte (0xC0) instead. Also fixes a crash where setRotation()
    and the async directTransfer() xfer task raced on the shared QSPI bus,
    desyncing the SPI driver's chip-select tracking.
    [AMOLEDDisplay.cpp]
2026-07-19 fix: enable ESP-NOW sync for WiiChuck-less device pairs
    Add network.forceController config option so two purely-autonomous
    devices (no WiiChuck/gesture input) can still sync over ESP-NOW: one
    device is marked as controller and broadcasts, the other follows.
    Also fixes two bugs found while wiring this up:
    - EyeSyncManager::begin() never called esp_wifi_set_channel(), so the
    configured network.channel never actually moved the radio there,
    only the (unenforced) peer metadata field.
    - EyeAnimator::processNetworkInput() gated on m_input instead of
    isController(), so a forced controller with no physical input would
    still adopt a follower's echoed-back state, creating a mutual
    feedback l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
    [EyeAnimator.cpp, EyeAnimator.h, EyeSync.cpp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]
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
